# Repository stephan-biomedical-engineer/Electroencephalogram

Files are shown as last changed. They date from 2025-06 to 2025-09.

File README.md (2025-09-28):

# 🧠 Wearable EEG Device – Biomedical Instrumentation I

> A wearable EEG system for real-time brain activity monitoring, designed with embedded systems and IoT principles.

---

## 📚 Project Overview

This project presents a **wearable Electroencephalogram (EEG) device** developed for the **Biomedical Instrumentation I** course. It aims to acquire and process low-amplitude human brain signals (**5µV to 300µV**) across standard EEG frequency bands:

* **Delta (δ):** 0.5 – 4 Hz
* **Theta (θ):** 4 – 8 Hz
* **Alpha (α):** 8 – 13 Hz
* **Beta (β):** 13 – 30 Hz
* **Gamma (γ):** 30 – 100 Hz

This is a full-stack biomedical system, integrating **analog signal conditioning**, **high-resolution digital conversion**, and **wireless data transmission** for real-time EEG visualization.

<p align="center">
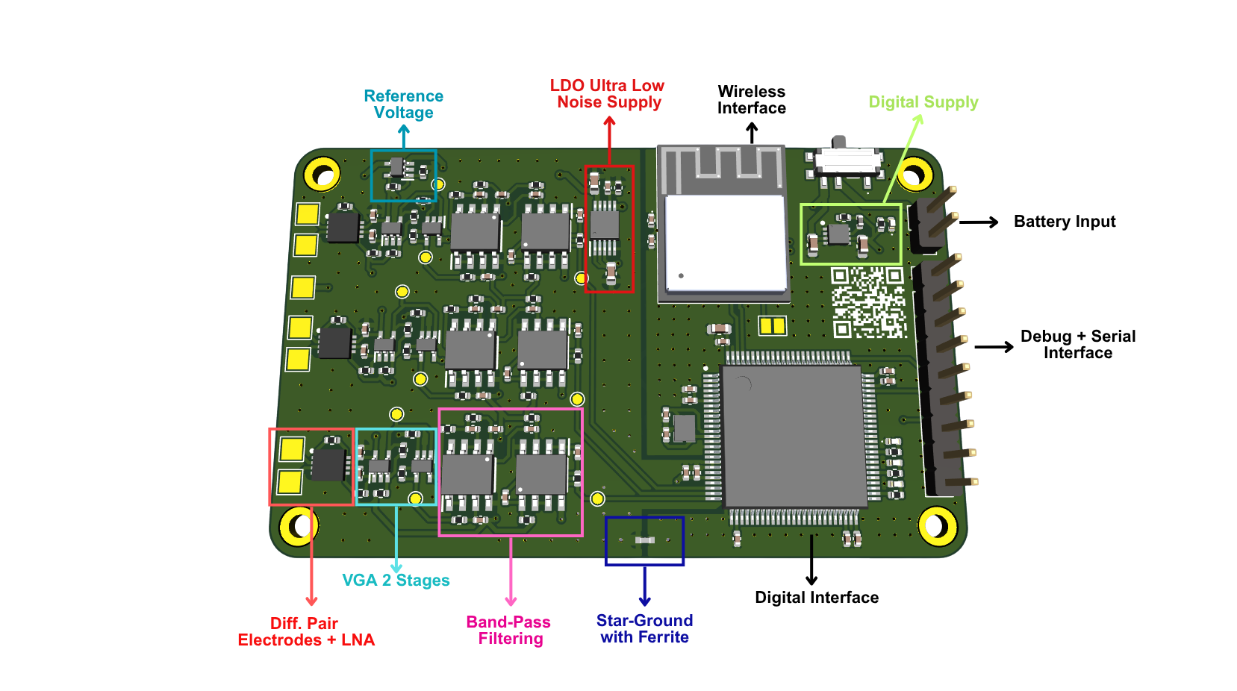
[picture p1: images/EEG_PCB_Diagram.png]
EEG Hardware Prototype
  
  <br>
  <b>EEG Hardware Prototype</b>
</p>

<p align="center">
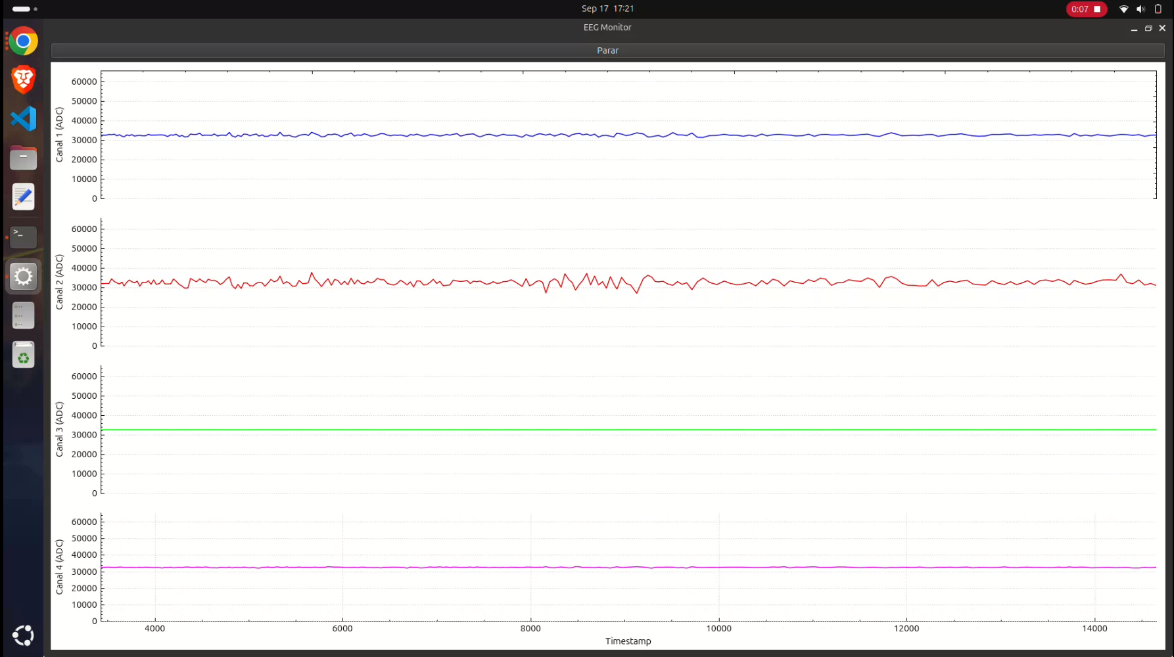
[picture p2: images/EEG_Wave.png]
Real-Time EEG Interface in Qt
  
  <br>
  <b>Real-Time EEG Interface in Qt</b>
</p>

<p align="center">
  Physical Setup
  <br>
  <b>Physical Setup</b>
</p>

---

## ⚙️ Hardware Architecture

### 🧩 Microcontroller Core

* **STM32H730VBT** SoC
* Features a **16-bit SAR ADC** up to **3.6 MSPS**, ideal for high-resolution EEG data acquisition.

### 🔌 Analog Front-End (AFE)

EEG signals are amplified \~**12000x** and filtered in a 3-stage analog pipeline:

1. **INA333 Instrumentation Amplifier** – 20x gain + initial passive filtering
2. **OPA333 Operational Amplifier** – 600x gain
3. **6th-Order Passive Bandpass Filter** – 0.5 Hz (HP) to 45 Hz (LP)

### 📡 Communication & Storage

* **External Flash:** W25Q512JV QSPI NOR Flash for firmware and logs
* **Wireless Co-Processor:** ESP32-C6-MINI-1H4, communicating via UART

---

## 💾 Firmware Architecture

### STM32H7 Side (Signal Acquisition)

* **DFSDM Peripheral** used for enhanced digital filtering
* **Oversampling & Bit Shifting** increase ADC ENOB
* Implements **Wavelet Transform** for real-time brain wave classification

### ESP32 Side (Wireless Stack)

* Developed using **ESP-IDF** and **FreeRTOS**
* Handles:

  * Serial communication with STM32
  * Data packetization
  * **Wi-Fi communication** to local host
  * **MQTT protocol** for lightweight IoT data streaming

---

## 🧪 Real-Time EEG Visualization

On the host side:

* A **Qt** interface provides live graphical feedback of EEG signals.
* Visualizes brain wave patterns and band activity in real time.

---

## 🛠️ Technologies Used

| Layer | Tools & Components |
| --- | --- |
| Microcontroller  | STM32H730VBT, STM32CubeIDE |
| Analog Circuitry | INA333, OPA333, RC Filters |
| Wireless | ESP32-C6, FreeRTOS (Not yet implemented) | 
| Protocols | UART, MQTT, Wi-Fi |
| Host Interface | Qt, C++, HTML5, WebSocket/MQTT |

---

## 🚧 Future Improvements

* ✅ Integrate live FFT for spectral analysis
* ✅ Mobile dashboard version
* 🔲 Dry electrodes support
* 🔲 Artifact rejection (e.g., blink/motion noise)
* 🔲 Bluetooth Low Energy (BLE) alternative

---

## 👨‍🔬 Authors & Acknowledgments
Stephan Costa Barros - 
Electrical Engineering Department – Federal University of Uberlândia (UFU), Brazil

Marcelo Barros de Almeida - 
Electrical Engineering Department – Federal University of Uberlândia (UFU), Brazil

Alcimar Barbosa Soares - 
Electrical Engineering Department – Federal University of Uberlândia (UFU), Brazil

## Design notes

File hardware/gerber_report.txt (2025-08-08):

Plotted to '/home/stephan/Documents/IB1/EEG_Light/Gerber/eeg-F_Cu.gbr'.
Plotted to '/home/stephan/Documents/IB1/EEG_Light/Gerber/eeg-In1_Cu.gbr'.
Plotted to '/home/stephan/Documents/IB1/EEG_Light/Gerber/eeg-In2_Cu.gbr'.
Plotted to '/home/stephan/Documents/IB1/EEG_Light/Gerber/eeg-B_Cu.gbr'.
Plotted to '/home/stephan/Documents/IB1/EEG_Light/Gerber/eeg-F_Paste.gbr'.
Plotted to '/home/stephan/Documents/IB1/EEG_Light/Gerber/eeg-B_Paste.gbr'.
Plotted to '/home/stephan/Documents/IB1/EEG_Light/Gerber/eeg-B_Silkscreen.gbr'.
Plotted to '/home/stephan/Documents/IB1/EEG_Light/Gerber/eeg-F_Mask.gbr'.
Plotted to '/home/stephan/Documents/IB1/EEG_Light/Gerber/eeg-B_Mask.gbr'.
Plotted to '/home/stephan/Documents/IB1/EEG_Light/Gerber/eeg-Edge_Cuts.gbr'.
Created Gerber job file '/home/stephan/Documents/IB1/EEG_Light/Gerber/eeg-job.gbrjob'.
Info: Done.

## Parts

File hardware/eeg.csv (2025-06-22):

Reference | Value | Footprint | Qty | DNP | Mouser Part Number
C1,C2,C3,C4,C5,C6,C10 | 100nF | Capacitor_SMD:C_0402_1005Metric | 7 |  | 581-0402X7R104KT7AT
C6 | 10uF | Capacitor_SMD:C_0402_1005Metric | 1 |  | 581-KGM05CS60J106MH
C7 | 1uF | Capacitor_SMD:C_0402_1005Metric | 1 |  | 581-04023D105KAT2A
C8,C9 | 2.2uF | Capacitor_SMD:C_0402_1005Metric | 2 |  | 581-04026D105MAT4A
C11 | 4.7uF | Capacitor_SMD:C_0402_1005Metric | 1 |  | 581-04026D475MAT2A
C12,C19,C20,C28,C29,C37,C38,C46,C47 | 0.1uF | Capacitor_SMD:C_0402_1005Metric | 9 |  | 581-0402X7R104KT7AT
C13,C14,C17,C18 | 20pF | Capacitor_SMD:C_0402_1005Metric | 4 |  | 77-VJ0402D200FXCAJ
C15,C16 | 1.8pF | Capacitor_SMD:C_0402_1005Metric | 2 |  | 581-0402YA1R8BAT2A
C21,C30,C39,C48 | 330nF | Capacitor_SMD:C_0402_1005Metric | 4 |  | 81-GRT155C80J334KE1J
C22,C24,C31,C33,C40,C41,C49,C51 | 36nF | Capacitor_SMD:C_0402_1005Metric | 8 |  | 81-GRM3195C2A363JA1D
C23,C32,C42,C50 | 8.2nF | Capacitor_SMD:C_0402_1005Metric | 4 |  | 581-0402YC822MAT2A
C25,C26,C27,C34,C35,C36,C43,C44,C45,C52,C53,C54 | 300nF | Capacitor_SMD:C_0402_1005Metric | 12 |  | 581-06035D334KAT2A
IC1 | STM32H730VBT6 | stm32h730vbt6:QFP50P1600X1600X160-100N | 1 |  | 511-STM32H730VBT6
IC2 | WF200D | wf200d:QFN40P400X400X90-33N-D | 1 |  | 634-WF200D
IC3,IC7,IC11,IC15 | INA333AIDRGT | ina333:SON50P300X300X80-9N-D | 4 |  | 595-INA333AIDRGT
IC4,IC8,IC12,IC16 | OPA333AIDCKRG4 | opa333:SOT65P210X110-5N | 4 |  | 595-OPA333AIDCKRG4
IC5,IC6,IC9,IC10,IC13,IC14,IC17,IC18 | MCP602-E_SN | mcp602:SOIC127P600X175-8N | 8 |  | 579-MCP602-E/SN
J1 | USB4105-GF-A | USB4105-GF-A:GCT_USB4105-GF-A | 1 |  | 640-USB4105-GF-A
J2 | -- mixed values -- | -- mixed values -- | 1 | DNP
L1 | 3.9nH | Inductor_SMD:L_0402_1005Metric | 1 |  | 70-IFCB0402ER3N9S
R1 | 1k | Resistor_SMD:R_0402_1005Metric | 1 |  | 667-ERA-2ARC102X
R2,R5 | 10k | Resistor_SMD:R_0402_1005Metric | 2 |  | 71-CRCW040210K0FKEDC
R3,R4 | 47 | Resistor_SMD:R_0402_1005Metric | 2 |  | 755-SFR01MZPJ470
R6 | 50 | Resistor_SMD:R_0402_1005Metric | 1 |  | 755-SFR01MZPJ470
R7,R17,R27,R37 | 5.26k | Resistor_SMD:R_0402_1005Metric | 4 |  | 71-CRCW04025K23FKEDC
R8,R18,R28,R38 | 910k | Resistor_SMD:R_0402_1005Metric | 4 |  | 594-MCS04020D9101BE0
R9,R19,R29,R39 | 5k | Resistor_SMD:R_0402_1005Metric | 4 |  | 603-RC0402FR-075KL
R10,R20,R30,R40 | 995k | Resistor_SMD:R_0402_1005Metric | 4 |  | 279-CRGCQ0402J1M0
R11,R21,R31,R41 | 97k | Resistor_SMD:R_0402_1005Metric | 4 |  | 660-RK73G1ETTP9762F
R12,R22,R32,R42 | 149K | Resistor_SMD:R_0402_1005Metric | 4 |  | 660-RN73R1TP1493D25
R13,R23,R33,R43 | 276K | Resistor_SMD:R_0402_1005Metric | 4 |  | 660-RN73R1TP2773B25
R14,R24,R34,R44 | 967k | Resistor_SMD:R_0402_1005Metric | 4 |  | 594-MCS04020C9763FE0
R15,R25,R35,R45 | 1.93M | Resistor_SMD:R_0402_1005Metric | 4 |  | 667-ERJ-U02F2004X
R16,R26,R36,R46 | 484k | Resistor_SMD:R_0402_1005Metric | 4 |  | 71-CRCW0402487KFKEDC
SW1,SW2 | SW_Push | sw_push:COM12992 | 2 |  | 474-COM-12992
U1 | USBLC6-2SC6 | Package_TO_SOT_SMD:SOT-23-6 | 1 |  | 511-USBLC6-2SC6
Y1 | 30MHz | crystal30M:830107284409 | 1 |  | 710-830107284409
Y2 | 38.4MHz | crystal38M4:CX1612DB38400H0FLJCC | 1 |  | 581-CX1612DB38400H0F

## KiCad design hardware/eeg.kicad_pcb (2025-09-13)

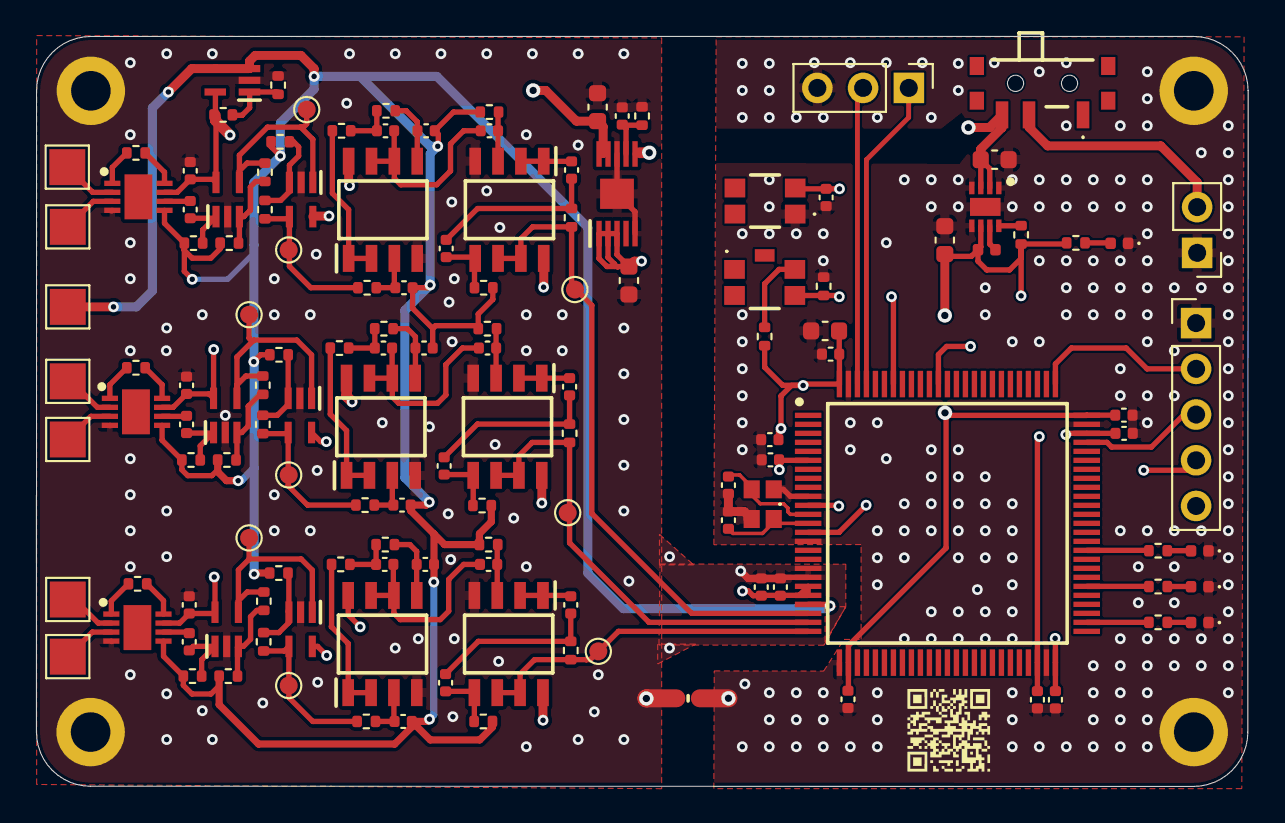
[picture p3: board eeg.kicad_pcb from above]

Board: 4 copper layers, 67.3 x 41.7 mm, 141 parts (0 on the bottom side), 89 nets.

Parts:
C1, C9, C17, C39: 0.1uF; C_0402_1005Metric
C2, C10, C18: 330nF; C_0402_1005Metric
C3, C5, C11, C13, C19, C21: 36nF; C_0402_1005Metric
C4, C12, C20: 8.2nF; C_0402_1005Metric
C6, C7, C8, C14, C15, C16, C22, C23, C24: 300nF; C_0402_1005Metric
C25, C26, C27, C28, C29, C31, C35: 100nF; C_0402_1005Metric
C30, C40, C42: 4.7uF; C_0603_1608Metric
C32: 1uF; C_0402_1005Metric
C33, C34: 2.2uF; C_0402_1005Metric
C37, C38: 20pF; C_0402_1005Metric
C41: 0.47uF; C_0402_1005Metric
C43: 10uF; C_0603_1608Metric
C44: 22uF; C_0603_1608Metric
CH1+, CH1-, CH2+, CH2-, CH3+, CH3-: TestPoint; TestPoint_Pad_2.0x2.0mm
D1, D2, D3, D4: LED; LED_0402_1005Metric
FB1: FerriteBead_Small; BEADC1005X55N
H1, H2, H3, H4: MountingHole_Pad; MountingHole_2.2mm_M2_DIN965_Pad
IC1: TPS62162QDSGRQ1; SON50P200X200X80-9N
IC2: LT3042IMSE#PBF; SOP50P490X110-11N
IC3: STM32H730VBT6; QFP50P1600X1600X160-100N
IC4: OPA333AIDCKRG4; SOT65P210X110-5N
J1: Battery LiPO; PinHeader_1x02_P2.54mm_Vertical
J2: Conn_01x05; PinHeader_1x05_P2.54mm_Vertical
J4: Serial; PinHeader_1x03_P2.54mm_Vertical
L1: 2.2uH; L_0402_1005Metric
R1, R2: 1M; R_0402_1005Metric
R3, R15, R27: 2.04k; R_0402_1005Metric
R4, R16, R28: 910k; R_0402_1005Metric
R5, R7, R17, R19, R29, R31: 1.5k; R_0402_1005Metric
R6, R8, R18, R20, R30, R32: 750k; R_0402_1005Metric
R9, R21, R33: 97k; R_0402_1005Metric
R10, R22, R34: 149K; R_0402_1005Metric
R11, R23, R35: 276K; R_0402_1005Metric
R12, R24, R36: 967k; R_0402_1005Metric
R13, R25, R37: 1.93M; R_0402_1005Metric
R14, R26, R38: 484k; R_0402_1005Metric
R39, R40, R41, R42, R44: 1k; R_0402_1005Metric
R43: 10k; R_0402_1005Metric
R45: 33.2k; R_0402_1005Metric
R46: 100k; R_0402_1005Metric
REF: TestPoint; TestPoint_Pad_2.0x2.0mm
S1: PCM12SMTBR
SW2: SW_Push_Dual; TL1030AF160BQJ
SW3: SW_Push_Dual; TL1030AF350AQJ
TP1, TP2, TP3, TP4, TP5, TP6, TP7, TP8, TP9: TestPoint; TestPoint_Pad_D1.0mm
U1, U5, U9: INA333xxDRG; SON50P300X300X80-9N-D
U2, U6, U10, U17, U18, U19: OPA333xxDCK; SOT65P210X110-5N
U3, U4, U7, U8, U11, U12: MCP602; SOIC127P600X175-8N
Y1: Crystal_GND24_Small; 830107284409

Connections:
ADC_IN1: IC3.25 (PA3), R14.1, TP3.1, U4.6 (-), U4.7
ADC_IN2: IC3.24 (PA2), R26.1, TP6.1, U8.6 (-), U8.7
ADC_IN3: IC3.23 (PA1), R38.1, TP9.1, U12.6 (-), U12.7
BOOT: IC3.94 (BOOT0), R43.2, SW2.4
EEG_CH1+: CH1+.1, U1.3 (+)
EEG_CH1-: CH1-.1, U1.2 (-)
EEG_CH2+: CH2+.1, U5.3 (+)
EEG_CH2-: CH2-.1, U5.2 (-)
EEG_CH3+: CH3+.1, U9.3 (+)
EEG_CH3-: CH3-.1, U9.2 (-)
GND: C25.2, C26.2, C27.2, C28.2, C29.2, C30.2, C33.2, C34.2, C35.2, C37.2, C38.2, C39.2, C43.2, C44.2, D1.1 (K), D2.1 (K), D3.1 (K), D4.1 (K), FB1.1, H3.1, H4.1, IC1.1 (PGND), IC1.4 (AGND), IC1.5 (FB), IC1.9 (EP), IC3.10 (VSS_1), IC3.15 (PC0), IC3.26 (VSS_2), IC3.49 (VSS_3), IC3.74 (VSS_4), IC3.99 (VSS_5), J1.1, J2.1, J4.3, R43.1, SW3.1, Y1.2, Y1.4
GNDA: C1.1, C9.1, C17.1, C31.2, C32.2, C40.2, C41.2, C42.2, FB1.2, H1.1, H2.1, IC2.5 (ILIM), IC2.8 (GND_1), IC2.11 (GND_2), IC3.18 (PC3_C), IC3.19 (VSSA), IC4.2 (V-), R2.1, R45.2, U1.4 (V-), U2.2 (V-), U3.4 (V-), U4.4 (V-), U5.4 (V-), U6.2 (V-), U7.4 (V-), U8.4 (V-), U9.4 (V-), U10.2 (V-), U11.4 (V-), U12.4 (V-), U17.2 (V-), U18.2 (V-), U19.2 (V-)
HSE_I: C37.1, IC3.12 (PH0-OSC_IN), Y1.1
HSE_O: C38.1, IC3.13 (PH1-OSC_OUT), Y1.3
LED_1: IC3.60 (PD13), R39.1
LED_2: IC3.56 (PD9), R40.1
LED_3: IC3.52 (PB13), R41.1
MCU_RX: IC3.97 (PE0), J4.1
MCU_TX: IC3.98 (PE1), J4.2
unnamed: C2.1, U1.6
unnamed: C5.1, R10.1, R11.1
unnamed: C7.1, C8.2, R14.2
unnamed: C10.1, U5.6
unnamed: C13.1, R22.1, R23.1
unnamed: C15.1, C16.2, R26.2
unnamed: C18.1, U9.6
unnamed: C21.1, R34.1, R35.1
unnamed: C23.1, C24.2, R38.2
unnamed: D1.2 (A), R44.2
unnamed: D2.2 (A), R39.2
unnamed: D3.2 (A), R40.2
unnamed: D4.2 (A), R41.2
unnamed: IC1.8 (PG), R46.1
unnamed: IC1.7 (SW), L1.1
unnamed: C41.1, IC2.7 (SET), R45.1
unnamed: IC4.1 (+IN), R1.1, R2.2
unnamed: R3.1, U1.8 (Rg)
unnamed: R3.2, U1.1 (Rg)
unnamed: R8.2, R9.1, TP2.1, U17.4
unnamed: R15.1, U5.8 (Rg)
unnamed: R15.2, U5.1 (Rg)
unnamed: R20.2, R21.1, TP5.1, U18.4
unnamed: R27.1, U9.8 (Rg)
unnamed: R27.2, U9.1 (Rg)
unnamed: R32.2, R33.1, TP8.1, U19.4
unnamed: R42.1, SW2.2
unnamed: C2.2, R4.1, U2.1 (+)
unnamed: R5.1, R6.1, U2.3 (-)
unnamed: C3.1, R9.2, U3.3 (+)
unnamed: R10.2, U3.1, U3.2 (-)
unnamed: C4.1, R11.2, U3.5 (+)
unnamed: C5.2, C6.2, U3.6 (-), U3.7
unnamed: C6.1, R12.2, U4.3 (+)
unnamed: C7.2, U4.1, U4.2 (-)
unnamed: C8.1, R13.2, U4.5 (+)
unnamed: C10.2, R16.1, U6.1 (+)
unnamed: R17.1, R18.1, U6.3 (-)
unnamed: C11.1, R21.2, U7.3 (+)
unnamed: R22.2, U7.1, U7.2 (-)
unnamed: C12.1, R23.2, U7.5 (+)
unnamed: C13.2, C14.2, U7.6 (-), U7.7
unnamed: C14.1, R24.2, U8.3 (+)
unnamed: C15.2, U8.1, U8.2 (-)
unnamed: C16.1, R25.2, U8.5 (+)
unnamed: C18.2, R28.1, U10.1 (+)
unnamed: R29.1, R30.1, U10.3 (-)
unnamed: C19.1, R33.2, U11.3 (+)
unnamed: R34.2, U11.1, U11.2 (-)
unnamed: C20.1, R35.2, U11.5 (+)
unnamed: C21.2, C22.2, U11.6 (-), U11.7
unnamed: C22.1, R36.2, U12.3 (+)
unnamed: C23.2, U12.1, U12.2 (-)
unnamed: C24.1, R37.2, U12.5 (+)
unnamed: R6.2, TP1.1, U2.4, U17.1 (+)
unnamed: R7.1, R8.1, U17.3 (-)
unnamed: R18.2, TP4.1, U6.4, U18.1 (+)
unnamed: R19.1, R20.1, U18.3 (-)
unnamed: R30.2, TP7.1, U10.4, U19.1 (+)
unnamed: R31.1, R32.1, U19.3 (-)
RESET: C39.1, IC3.14 (NRST), SW3.2
SWCLK: IC3.76 (PA14), J2.2
SWDIO: IC3.72 (PA13), J2.3
SWO: IC3.89 (PB3), J2.4
VCAP: C33.1, C34.1, IC3.48 (VCAP_1), IC3.73 (VCAP_2)
VDD33: C25.1, C26.1, C27.1, C28.1, C29.1, C30.1, C35.1, C44.1, IC1.6 (VOS), IC3.6 (VBAT), IC3.11 (VDD_1), IC3.27 (VDD_2), IC3.50 (VDD_3), IC3.75 (VDD_4), IC3.100 (VDD_5), J2.5, L1.2, R42.2, R44.1, R46.2
VDDA33: C1.2, C9.2, C17.2, C31.1, C32.1, C42.1, IC2.9 (OUTS), IC2.10 (OUT), IC3.20 (VREF+), IC3.21 (VDDA), IC4.5 (V+), R1.2, U1.7 (V+), U2.5 (V+), U3.8 (V+), U4.8 (V+), U5.7 (V+), U6.5 (V+), U7.8 (V+), U8.8 (V+), U9.7 (V+), U10.5 (V+), U11.8 (V+), U12.8 (V+), U17.5 (V+), U18.5 (V+), U19.5 (V+)
VIN_BAT: C40.1, C43.1, IC1.2 (VIN), IC1.3 (EN), IC2.1 (IN_1), IC2.2 (IN_2), IC2.3 (EN/UV), IC2.6 (PGFB), S1.3 (NO)
VIN_SWT: J1.2, S1.2 (COM)
VREF: C3.2, C4.2, C11.2, C12.2, C19.2, C20.2, IC3.22 (PA0), IC4.3 (-IN), IC4.4 (OUT), R4.2, R5.2, R7.2, R12.1, R13.1, R16.2, R17.2, R19.2, R24.1, R25.1, R28.2, R29.2, R31.2, R36.1, R37.1, REF.1, U1.5 (Ref), U5.5 (Ref), U9.5 (Ref)

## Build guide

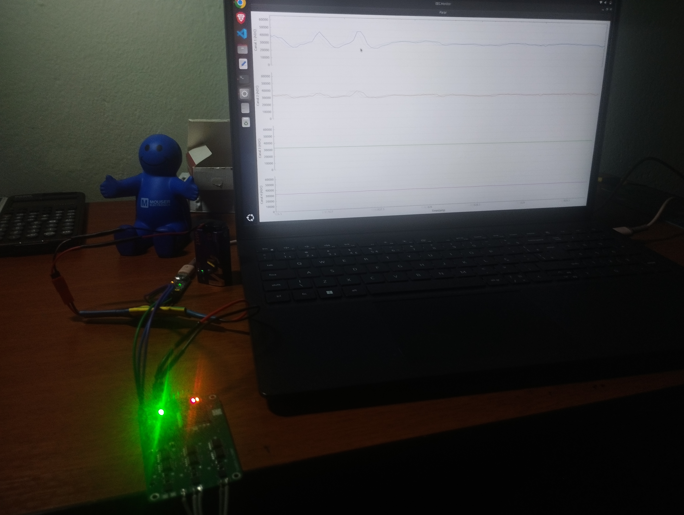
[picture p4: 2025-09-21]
images/Setup.jpg

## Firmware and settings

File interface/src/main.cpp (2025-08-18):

#include <QApplication> // Use QApplication, não QCoreApplication
#include "mainwindow.h"

int main(int argc, char *argv[])
{
    // QApplication é a classe de aplicação para GUI
    QApplication a(argc, argv);

    // Cria a janela principal e a exibe
    MainWindow w;
    w.show();

    // Inicia o loop de eventos da aplicação
    return a.exec();
}

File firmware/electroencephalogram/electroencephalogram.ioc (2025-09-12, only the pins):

Mcu.UserName=STM32H730VBTx
PA0.Signal=ADC1_INP16
PA1.Signal=ADC1_INP17
PA13(JTMS/SWDIO).Signal=DEBUG_JTMS-SWDIO
PA14(JTCK/SWCLK).Signal=DEBUG_JTCK-SWCLK
PA2.Signal=ADCx_INP14
PA3.Signal=ADCx_INP15
PA6.Signal=OCTOSPIM_P1_IO3
PA7.Signal=OCTOSPIM_P1_IO2
PB1.Signal=OCTOSPIM_P1_IO0
PB13.Signal=GPIO_Output
PB2.Signal=OCTOSPIM_P1_CLK
PB3(JTDO/TRACESWO).Signal=DEBUG_JTDO-SWO
PD13.Signal=GPIO_Output
PD9.Signal=GPIO_Output
PE0.Signal=UART8_RX
PE1.Signal=UART8_TX
PE7.GPIO_Label=RESET_FLASH
PE7.Signal=GPIO_Output
PH0-OSC_IN.Signal=RCC_OSC_IN
PH1-OSC_OUT.Signal=RCC_OSC_OUT

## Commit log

2025-06-22 EEG first commit
    [eeg.csv, eeg.kicad_pcb, eeg.kicad_sch]
2025-06-22 KiCAD libraries includes
2025-07-06 firmware ESP32
2025-07-06 Firmware LED ESP32
2025-08-04 hardware final update
    [afe.kicad_sch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]
2025-08-08 Final Hardware Implementation
    [afe.kicad_sch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]
2025-08-18 CRC+COBS+UART+ADC+CBF implementation
2025-09-06 UART DMA inclusion
2025-09-12 Interface com FFT
    [afe.kicad_sch]
2025-09-13 ADC Calibration Stage
2025-09-13 Hardware att
    [eeg.kicad_pcb]
2025-09-21 Hardware v1 final version
    [afe.kicad_sch]
